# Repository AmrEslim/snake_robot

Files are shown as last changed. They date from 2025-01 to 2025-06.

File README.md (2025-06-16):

# snake_robot
# 🐍 Neurobiologically inspired control of a robot: Development and Control Strategies

This repository contains the development, design, and control strategies for a **Neurobiologically inspired control of a robot**, built as a Bachelor's thesis. The project focuses on **mechanical design, motion control, and CPG-based locomotion strategies**.

## 📖 Overview
The project explores:
- 🦴 **Hardware Design**: Modular snake-like body segments, 3D-printed joints.
- 🧠 **Control Strategies**: Central Pattern Generators (CPGs), Reinforcement Learning.
- 🎮 **Tests**: with Kinovea motion tracking.
- 🔬 **Experiments & Results**: Performance analysis, real-world testing.

## 📂 Repository Structure
📂 **hardware/** - STL files, electronics, and mechanical schematics  
📂 **software/** - Arduino IDE code control algorithms  
📂 **docs/** - Detailed documentation (see the [Wiki](https://github.com/AmrEslim/snake_robot/wiki))  
📂 **media/** - Photos, videos, and results

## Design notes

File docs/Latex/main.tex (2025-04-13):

\documentclass[12pt,a4paper]{report}
\usepackage[a4paper, margin=2.5cm]{geometry} 
\usepackage{graphicx}
\usepackage{float}
\usepackage[hidelinks]{hyperref}
\usepackage{amsmath, amssymb}
\usepackage{listings}
\usepackage[backend=biber,style=ieee,sorting=nty,maxnames=1,minnames=1]{biblatex}
\usepackage{csquotes}
\usepackage{algorithm}
\usepackage{algpseudocode}
\usepackage[utf8]{inputenc}
\usepackage{placeins}
\usepackage{float}
\usepackage{pgfplots}
\usepgfplotslibrary{units}
\usepackage{tikz}
\usepackage{minted}
\usepackage{xmpmulti}
\usepackage{animate}
\usepackage{multido}
\usepackage{svg}
\usetikzlibrary{snakes}
\usepackage{adjustbox}
\usepackage{pdfpages} 
\usepackage{chngcntr}
\usepackage{times}          % For Times New Roman font
\usepackage{microtype}      % For better typography in justified text
\usepackage{fancyhdr}       % For header and footer
\usepackage{ragged2e}       % For better justification
\usepackage{titlesec}       % For heading formatting
% Document settings according to university requirements
\renewcommand{\baselinestretch}{1.3}  % Line spacing between 1 and 1.3
\setlength{\parindent}{0pt}           % No paragraph indentation
\setlength{\parskip}{6pt}             % Paragraph spacing

% Make sure figures and tables are numbered continuously
\counterwithout{figure}{chapter}
\counterwithout{table}{chapter}
% Justify text with hyphenation
\hyphenpenalty=1000
\tolerance=1000
\emergencystretch=\maxdimen
\hbadness=10000
\doublehyphendemerits=10000
\finalhyphendemerits=5000

% Format chapter and section headings to make them stand out
\titleformat{\chapter}[display]
{\normalfont\huge\bfseries}{\chaptertitlename\ \thechapter}{20pt}{\Huge}
\titleformat{\section}
{\normalfont\large\bfseries}{\thesection}{1em}{}
\titlespacing*{\chapter}{0pt}{50pt}{40pt}
% Set up headers and footers
\pagestyle{fancy}
\fancyhf{}
\fancyhead[L]{\leftmark}    % Chapter name in the header
\fancyhead[R]{\thepage}     % Page number in the header
\renewcommand{\headrulewidth}{0.4pt}
\fancypagestyle{plain}{     % Style for chapter pages
  \fancyhf{}
  \fancyfoot[C]{\thepage}
  \renewcommand{\headrulewidth}{0pt}
}

\addbibresource{references.bib}

% Document settings following HTW guidelines
\renewcommand{\baselinestretch}{1.5}  % 1.5 line spacing
\setlength{\parindent}{0pt}  % No paragraph indentation
\setlength{\parskip}{6pt}    % Paragraph spacing

\titleformat{\chapter}[hang]
  {\normalfont\bfseries\Large}{\thechapter.}{10pt}{}

\begin{document}
% Include the title page
% Include the title page
\begin{titlepage}
    \centering
    \vspace*{0.5cm}
    % University logo at the top
    

    \vspace{1cm}
    \rule{\linewidth}{0.5mm}\\[0.4cm]
    {\Huge \textbf{Neurobiologically inspired control of a robot}}\\[0.3cm]
    \rule{\linewidth}{0.5mm}\\[1.5cm]

    {\LARGE Bachelorarbeit}\\[1.0cm]

    {\Large Computer Engineering}\\[1cm]

    {\large vorgelegt von}\\[0.3cm]
    {\Large Amr Eslim}\\[0.8cm]

    {\large Fachbereich 1}\\[1.0cm]

    {\large \textbf{Datum:}}\\
    {\large Berlin, \today}\\[1.0cm]

    {\large \textbf{Erstgutachter:} Prof. Dr. Jochen Kerdels}\\[0.3cm]
    {\large \textbf{Zweitgutachter:} Prof. Dr. Frank Bauernöppel}\\[1.5cm]

    % \includegraphics[width=0.3\textwidth]{media/snake_robot.jpg}
\end{titlepage}

\begin{abstract}
This thesis presents the design, implementation, and experimental evaluation of a neurobiologically inspired snake-like robot. Drawing from the locomotion mechanisms observed in biological snakes, the research develops a modular robotic system capable of executing multiple biologically authentic movement patterns. The work focuses on implementing Central Pattern Generator (CPG) inspired control algorithms to generate coordinated undulatory movements across the robot's segmented body. A 10-servo design with alternating horizontal and vertical actuation planes enables both lateral undulation and sidewinding locomotion patterns. The system utilizes an ESP32 microcontroller with WiFi connectivity to provide real-time control and parameter adjustment through a web-based interface. Three distinct robot configurations (baseline, with TPU-printed scales, and with PLA+ printed wheels) are experimentally evaluated to determine their effects on locomotion performance and energy consumption. Motion tracking analysis reveals differences in movement patterns between configurations, with wheels providing the most uniform progression during lateral undulation. Energy consumption measurements demonstrate that sidewinding requires more power than lateral undulation, and friction elements increase power requirements as well. The findings highlight the complex interplay between mechanical configuration, control parameters, and environmental interactions in biomimetic locomotion. This research contributes to the field of bioinspired robotics by providing insight into the design principles and control strategies for effective snake-like locomotion, with potential applications in search and rescue, pipeline inspection, and educational contexts.
\end{abstract}

\includepdf[pages=-]{Eigenstaendigkeitserklaerung.pdf}
% Start Roman numeral page numbering
\pagenumbering{Roman}
% Table of Contents
\tableofcontents
\listoffigures
\newpage
\listoftables
\newpage
% Start Arabic numeral page numbering with Introduction
\cleardoublepage
\pagenumbering{arabic}
%//////////////////
%//////////////////
%chapter 1
%//////////////////
%//////////////////
\chapter{ Introduction}
Snake-like robots represent a fascinating intersection of biological inspiration and robotic engineering, offering unique mobility solutions for complex environments. This chapter establishes the foundation for understanding bio-inspired snake robotics, examining the research context, motivations, and key objectives that drive this field forward. 

\section{Background and Motivation}
Snake robots have emerged as a promising technological innovation inspired by the locomotion mechanisms observed in biological snakes. These robots exhibit exceptional adaptability in navigating confined spaces and overcoming challenging terrains where conventional wheeled or legged robots struggle. Their unique ability to generate smooth and continuous movements makes them particularly suitable for applications such as search-and-rescue missions, pipeline inspection, and medical procedures requiring minimally invasive interventions \cite{transeth-2009, Hirose2004}.

The fundamental advantage of snake-like robots lies in their ability to replicate the efficient and versatile locomotion strategies of real snakes. By leveraging undulatory movements, these robots can traverse irregular surfaces, maneuver through narrow gaps, and maintain stability on diverse terrain \textcite{Seeja2022}. The inspiration from biological systems, coupled with advances in robotic control, has led to significant progress in the field, paving the way for innovative robotic applications.

\section{Research Objectives}
This research aims to contribute to the development of bio-inspired snake robots by focusing on the following key objectives:

\begin{itemize}
    \item Design and construct a modular snake robot with multiple degrees of freedom to enable flexible and adaptive movement.
    \item Develop and optimize biologically inspired control algorithms to achieve efficient and stable locomotion.
    \item Implement and evaluate different motion patterns, including lateral undulation and serpentine locomotion, to enhance adaptability across various environments.
    \item Analyze the robot's performance metrics across different terrain types to assess its effectiveness and versatility.
    \item Integrate a robust hardware and software control system to ensure reliable operation and real-time adaptability in dynamic conditions.
\end{itemize}

\section{Paper Structure}
Following the introduction, this thesis proceeds with a chapter on the state of the art, covering biological principles of snake locomotion as well as the historical development and current research status on snake robots and CPG networks. The third chapter presents the system design and implementation of the snake robot, including mechanical construction using Onshape, 3D printing, and integration of the ESP32 microcontroller with ten servo motors. The fourth chapter details the experimental results, analyzing movement patterns and power consumption. Finally, the thesis concludes with a summary of research findings, limitations of the current implementation, and suggestions for future improvements. Supplementary technical documentation regarding hardware and software is provided in the appendix.

%//////////////////
%//////////////////
%chapter 2
%//////////////////
%//////////////////
\chapter{State of the Art}

This chapter reviews the biological principles of snake locomotion, including natural movement patterns and biomechanics. It also explores the historical development and current state of snake robot research, covering simulation and modeling approaches, biologically inspired robotic designs, and neurological models for locomotion control.

\section{Biological Snake Locomotion}
Snake locomotion has been extensively studied as a foundation for bio-inspired robotics. According to \textcite{liljeback-2013}, snake motion can be characterized by several distinct patterns, each optimized for different environmental conditions and objectives. These patterns have been widely implemented in robotic systems to improve their adaptability and efficiency in traversing complex environments.
Further investigations have examined the biomechanical principles underlying these motion patterns, contributing to the development of advanced control strategies \cite{lamping-2022}.

\subsection{Natural Snake Movement Patterns}
The primary motion patterns observed in biological snakes include:

\subsubsection{Lateral Undulation}
Lateral undulation, also known as serpentine motion, is the most common form of snake locomotion \textcite{liljeback-2013}. In this pattern, the snake creates a series of smooth curves that propagate from head to tail, generating forward thrust through the interaction with ground irregularities. \textcite{liljeback-2013} describe this as a wave-like motion where the snake's body follows the path traced by its head, with each segment of the body following the same spatial curve but with a time delay. 

\subsubsection{Rectilinear Motion}
According to \textcite{Zhenli2006} rectilinear locomotion occurs when "the skin of the ventral surface is moved forward and backward by strong muscles and the broad belly scales grip the ground, moving the snake forward in a straight line." The authors note that this form of locomotion "is used only by the heavier-bodied snakes."

\subsubsection{Concertina Locomotion} Concertina locomotion is named after a small accordion instrument, illustrating how the snake periodically folds and stretches its body to move forward. In this gait, the snake will anchor part of its body against the ground (or against a tunnel wall, tree branch, etc.), while other sections extend forward, after which the newly extended portion forms a new anchor and pulls the rest of the body along \cite{Zhenli2006}. note that this pattern is especially prevalent in constrained or narrow spaces, and it is often used for crossing smooth surfaces or climbing where other gaits may prove less effective.

\subsubsection{Sidewinding}
Sidewinding is "probably the most astonishing gait to observe and is mostly used by snakes in the desert" \cite{transeth-2009}. During this locomotion, "the snake lifts and curves its body leaving short, parallel marks on the ground while moving at an inclined angle" \cite{transeth-2009}. Unlike other gaits like lateral undulation, sidewinding involves "brief static contact between the body of the snake and the ground" \cite{transeth-2009}. This movement pattern is particularly useful "on surfaces with low shear such as sand" where snakes can achieve velocities up to 3 km/h \cite{transeth-2009}.

\subsection{Biomechanical Principles}
The effectiveness of snake locomotion relies on several key physical principles:

\subsubsection{Friction Models}
  As \textcite{lamping-2022} thoroughly analyze, anisotropic friction is crucial for effective snake movement. The contrast in forward versus reverse friction coefficients drives directional locomotion. This principle is significant for designing snake robots, which often require artificial scales or surface modifications to mimic this property. These mechanisms that enhance friction in snake-like robots are vital to improving their ability to adapt to a wide range of surfaces.
 
\subsubsection{Propulsion Mechanics}
The generation of propulsive forces in snake locomotion is achieved through strategic interactions with environmental push-points, where reaction forces contribute to forward movement. \textcite{Bayraktaroglu2006} describe how a snake-like robot mimics natural lateral undulation by utilizing push-points in the environment. Each module follows its predecessor, ensuring coordinated motion, while the orientation of reaction forces determines the overall direction of movement. The applied motor control inputs facilitate continuous progression similar to biological snakes.
Additionally, rhythmic motion patterns are regulated by neuronal circuits known as Central Pattern Generators (CPGs), described further in Section \ref{sec:neurological_models}.

\section{Snake Robots: State of the Art}

This section examines the evolution of snake robotics from its inception to current state-of-the-art implementations, highlighting key developments in mechanical design, control strategies, and application domains.

\subsection{Historical Development}
The historical evolution of snake robotics commenced with Hirose's pioneering work in 1972, developing the Active Cord Mechanism (ACM III), which became the foundational design for snake robots. Hirose introduced the concept of modularity and redundancy, emphasizing adaptability to challenging terrains through serpentine motion patterns \cite{transeth-2009}. His initial robot designs featured serially connected joints capable of undulatory locomotion, thus setting a standard for robust, modular robotic systems \cite{Hirose2004}.

Building upon Hirose's foundational contributions, research diversified into wheeled and wheel-less robotic designs. Initially, passive wheels were utilized to facilitate smooth movements on structured surfaces; however, these were limited to artificially prepared environments \cite{Bayraktaroglu2006}. Subsequently, a shift toward wheel-less snake robots was driven by a desire to replicate natural snake locomotion more accurately, leading to advancements in mechanical and control innovations \cite{transeth-2009}.

\subsection{Current Research Directions}
Contemporary research in snake robotics is focused on enhancing locomotion efficiency, adaptability, and control mechanisms. Several key areas of investigation include:

\subsubsection{Control Systems}

Central Pattern Generators (CPGs) have been increasingly applied to snake-like robots for generating rhythmic movements. \textcite{Seeja2022} discuss CPG-based algorithms enabling robots to dynamically adjust trajectories, facilitating obstacle avoidance and smooth turning motions. Sensory feedback integration further improves collision detection and adaptive movement capabilities.

\subsubsection{Alternative Locomotion Strategies}
\textcite{yamano-2023} propose a rolling motion strategy for snake-like robots that enhances efficiency by utilizing a shift in the center of gravity (COG). Their approach divides the rolling motion into four distinct phases: (1) the kick stage, where the robot’s head or tail moves to initiate ground contact and generate rolling motion; (2) COG shift stage I, in which a heavier link at the head or tail moves forward to reposition the COG; (3) COG shift stage II, where the same link is raised to further adjust the COG; and (4) the rolling stage, where gravity facilitates continuous rolling motion.

\subsubsection{Mechanical Design and Adaptability}
The impact of mechanical parameters, particularly scale angles and friction coefficients, on the locomotion of snake robots has been extensively studied. Research by \textcite{shen-2021} demonstrated that the angle of the robot’s scales can be dynamically adjusted using air pressure, directly influencing its movement efficiency. Their experiments revealed that an optimal anchoring coefficient is achieved when the scale angle is around 26.7° at a pressure of 12 kPa, significantly improving forward propulsion. Conversely, when the pressure exceeds 22 kPa, the scales flip direction, enabling backward locomotion. This adaptive approach mimics biological snake adaptations by altering surface friction to enhance traction and maneuverability.

\subsection{Simulation and Modeling}
Accurate modeling is essential for designing and optimizing snake robot locomotion. \textcite{liljeback-2013} provide a foundational analysis of lateral undulation, introducing a simplified dynamic model for control design and stability analysis. Their study highlights that effective locomotion control must incorporate time-varying strategies, as static control laws fail to stabilize the system due to its inherent dynamics. Using averaging theory, they derived fundamental relationships between gait parameters and forward velocity, showing that the robot’s motion can be analytically predicted and optimized based on these parameters. This work has been instrumental in developing physics-based simulations that enable rapid prototyping and validation of locomotion strategies.

An additional contribution to simulation methodologies comes from \textcite{yogesh2023snake}, who provides open-source simulation tools for snake robot modeling. These practical implementations facilitate experimentation with different control strategies and locomotion patterns, supporting researchers in optimizing robot performance before physical deployment.

\subsection{Biologically Inspired Snake-like Robots}
Bio-inspired design principles continue to drive innovations in snake robotics. \textcite{Mohammed2016} developed a 3D printed modular snake robot that integrates flexible joint structures, enhancing both maneuverability and robustness. Their research highlights the benefits of modularity, where each module functions as a single rotational joint with one degree of freedom (DOF). The robot's structure allows for movement across multiple axes, enabling adaptability in various applications, such as search-and-rescue and medical robotics.

Building on this, \textcite{Arachchige2021} explored the potential of soft robotic snakes (SRS) by incorporating spatial bending capabilities to extend locomotion beyond conventional planar gaits. Their study demonstrates how continuous and smooth bending enables snake robots to better replicate biological movement, allowing for improved adaptability in climbing, swimming, and traversing complex terrains. These advancements highlight how soft robotics principles enhance maneuverability while maintaining structural integrity and operational efficiency.

\section{Neurological Models of Snake Locomotion}
\label{sec:neurological_models}
The locomotion of snakes has been extensively studied, revealing that their movement is governed by neural circuits that enables adaptive and rhythmic motion. This capability is controlled by Central Pattern Generators (CPGs), which are neural circuits responsible for generating rhythmic outputs without requiring continuous sensory feedback. These circuits, located within the spinal cord, play a fundamental role in orchestrating rhythmic behaviors such as walking, swimming, and crawling in both vertebrates and invertebrates \cite{MARDER2001R986}

\subsection{Central Pattern Generator (CPG) Model}

CPGs, fundamental to locomotion control, are extensively modeled to replicate the rhythmic patterns of snake locomotion. They typically comprise coupled neural oscillators that produce rhythmic signals with stable oscillations and phase-shifted outputs for coordinated joint movements \cite{wang2020cpg}. Various approaches to CPG modeling have been proposed:

\FloatBarrier
\subsubsection{Mutual Inhibitory CPGs}

One of the fundamental architectures for generating rhythmic motion is the mutual inhibitory CPG model shown in Figure~\ref{fig:mutual_inhibitory_cpg}, which consists of neuron pairs that reciprocally inhibit each other, leading to stable oscillations. This architecture ensures continuous rhythmic movement. However, it lacks adaptability to environmental variations because it does not inherently produce sustained oscillations without additional adaptation mechanisms \cite{Lu2006}.

\begin{figure}[H]
\centering
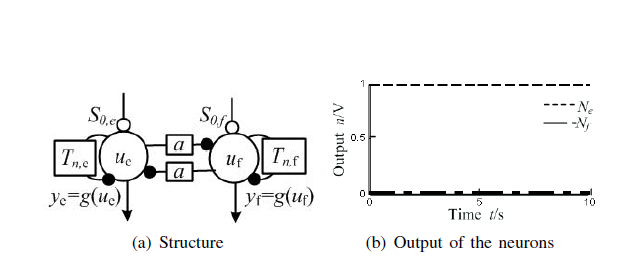
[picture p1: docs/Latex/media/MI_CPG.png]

\caption{Mutual inhibitory CPG model \cite{Lu2006}. This model illustrates pairs of neurons reciprocally inhibiting each other, creating stable rhythmic oscillations.}
\label{fig:mutual_inhibitory_cpg}
\end{figure}

\subsubsection{Cyclic Inhibitory CPGs}

Cyclic inhibitory CPG models address the limitations of mutual inhibitory architectures by incorporating feedback loops that enable the system to maintain oscillatory activity over time. These models involve interconnected neurons in a cyclic inhibitory structure (see Figure \ref{fig:cyclic_inhibitory_cpg}), allowing for sustained and coordinated oscillations. This design proves particularly effective in generating stable 3D locomotion, as it enhances phase synchronization across multiple joints. Studies have demonstrated the effectiveness of this model in achieving robust serpentine motion, making it a preferable choice for controlling the locomotion of snake-like robots \cite{Lu2006}.

\begin{figure}[H]
\centering
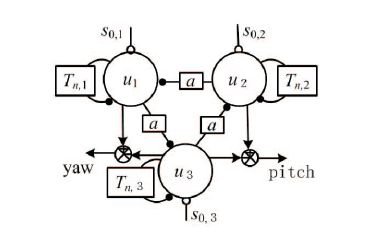
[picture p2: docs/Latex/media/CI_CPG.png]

\caption{Cyclic inhibitory CPG model \cite{Lu2006}}
\label{fig:cyclic_inhibitory_cpg}
\end{figure}

\subsubsection{Sensory Feedback-Integrated CPGs}
Recent advancements in CPG modeling incorporate sensory feedback mechanisms, allowing adaptive locomotion. These models integrate sensory information through sensory interneurons (SIN), which relay environmental data back to the CPG, enabling real-time adjustments to oscillatory parameters \cite{Inoue2007}. For instance, \textcite{Inoue2007} implemented a CPG-based control system where sensory input was processed by SIN and fed back into the CPG, enhancing the robot's ability to adapt to variations in ground friction.

\subsubsection{Evolutionary and Learning-Based CPGs}
Machine learning and evolutionary algorithms have been applied to optimize CPG parameters for snake locomotion. By employing genetic algorithms (GA), researchers have enabled robots to autonomously refine their locomotion patterns in response to different terrains and obstacles \cite{Inoue2007}. Specifically, \textcite{Inoue2007} used GA to evolve CPG parameters that maximize adaptability across varying friction conditions, demonstrating that multi-environment performance-based evaluation functions enhance adaptive locomotion.

\subsection{Implementation Considerations}
When implementing CPG-based control, several key factors must be considered:
\begin{itemize}
    \item Phase Relationships Between Segments: To achieve effective serpentine locomotion, it is essential to maintain a consistent phase difference between joint oscillations. This phase control ensures synchronized movement, allowing the robot to generate propulsion force through interactions with the ground \cite{Norzalilah2014}.
    \item Coupling Strengths Between Oscillators: The coordination between different segments of a CPG network is influenced by the strength of the connections between oscillators. Proper tuning of descending and ascending coupling pathways is necessary to ensure segmental synchronization, which requires detailed anatomical and electrophysiological studies \cite{MARDER2001R986}.
    \item Adaptation Mechanisms for Environmental Feedback: A robust CPG-based system must integrate sensory feedback to adapt to environmental variations. Sensory inputs, such as ground reaction forces or muscle length changes, can be fed back into the CPG network to enhance stability and improve locomotion resilience against disturbances \cite{Inoue2007}.
    \item Stability of Rhythm Generation: The stability of rhythmic motion depends on ensuring bounded and well-defined oscillatory behavior. Mathematical conditions such as Lipschitz continuity help establish the existence and uniqueness of stable rhythmic solutions in CPG models, preventing disruptions in locomotion patterns \cite{Zhenli2006}.
\end{itemize}

These models provide a foundation for developing bio-inspired control systems that can generate smooth, coordinated motion patterns while maintaining adaptability to environmental changes.

\subsection{Mathematical Representation of CPG Networks}

The neural control system of a snake-like robot can be mathematically modeled as a network of coupled oscillators. As described by \textcite{wang2020cpg}. each oscillator in the network represents a segmental neural circuit. The system is structured as a single-chain bidirectional coupling network, where each connection between oscillators is defined by a phase lag parameter. The network's dynamics are governed by the following set of differential equations:

\begin{equation}
    \dot{\theta}_k =
    \begin{cases} 
        2\pi v + w \sin(\theta_2 - \theta_1 + \phi), & k = 1 \\
        2\pi v + w \left[\sin(\theta_{k-1} - \theta_k - \phi) + \sin(\theta_{k+1} - \theta_k + \phi)\right], & 2 \leq k \leq N-1 \\
        2\pi v + w \sin(\theta_{N-1} - \theta_N - \phi), & k = N
    \end{cases}
\end{equation}

where \( \theta_k \) represents the phase of the \( k \)-th oscillator, \( v \) denotes the intrinsic oscillation frequency, and \( w \) is the coupling strength between oscillators. The output of each oscillator, corresponding to the joint angle in a snake-like robot, is given by:

\begin{equation}
    \phi_k = A \cos(\theta_k), \quad 1 \leq k \leq N
\end{equation}

where \( A \) represents the oscillation amplitude. This mathematical formulation provides a precise method for generating rhythmic movement, crucial for implementing bio-inspired locomotion strategies in snake-like robots \cite{wang2020cpg}.

%//////////////////
%//////////////////
%chapter 3
%//////////////////
%//////////////////

\chapter{System Design, Implementation, and Details}

This chapter presents the complete design and implementation of the bio-inspired snake robot, focusing on its hardware architecture, control system, and motion generation. Inspired by biological snake locomotion patterns, the system employs Central Pattern Generator (CPG)-based control strategies.

\section{Evolution of System Design}
The snake robot underwent several iterations, each driven by practical testing and the desire to overcome early design limitations. The first prototype was built around an STM32-L432KC microcontroller with only preprogrammed parameters, offering no interface to start, stop, or adjust the locomotion algorithm in real time. All circuitry, including the buck converters, was centralized in the head module, making it disproportionately large and heavy compared to the rest of the body. This imbalance placed excessive strain on the front servo motor, reducing maneuverability and overall efficiency.

Motivated by these limitations, a new approach centered on the ESP32 microcontroller was adopted. The ESP32 not only offers more capable processing but also provides built-in wireless connectivity, allowing for a WiFi-based interface to control motion parameters remotely. Beyond WiFi, the ESP32 facilitates future expansion via ESP-NOW for direct controller-to-controller links, making it possible to develop a dedicated handheld remote or integrate additional sensing modules without physical wiring. Familiarity with the ESP32 development environment and libraries further justified its selection over the STM32 platform.

In parallel with changing the microcontroller, the mechanical design was refined to address structural weaknesses. Rather than relying on a single contact point in each joint, two robust contact points were introduced, significantly improving stability and mitigating stresses that lead to early mechanical failures. A vertical joint was also added to enable out-of-plane motion, expanding the robot’s maneuverability beyond simple horizontal undulations and paving the way for more complex locomotion strategies.

\subsection{Distributed Power and Noise Mitigation}
Shifting the power architecture to a distributed design represented another key enhancement. Instead of locating all buck converters in the head, individual converters were placed near each servo motor. This arrangement reduced the length and complexity of wiring, requiring only a single power line routed from the battery to each converter. Although this layout made the design cleaner and lighter, it also introduced an issue with signal noise: the servos occasionally moved erratically or exhibited jitter.

A detailed investigation revealed that the combination of servo control signals and distributed power lines led to unwanted interference. To counteract this noise, a 16\,V/100\,$\mu$F capacitor was placed on each buck converter output, acting as a local power reservoir. Additionally, each servo signal line was equipped with a 10\,k$\Omega$ pull-down resistor, which helped stabilize the control signals. These hardware modifications effectively eliminated the jitter and restored precise servo actuation.

\subsection{Battery Selection and Current Sensing}
After refining the cabling and completing initial motion tests, it became evident that the chosen battery’s built-in current-limiting protection would occasionally trigger and power down the system. During peak load conditions, especially when multiple servos actuated simultaneously, the protection circuit perceived an overcurrent event and disconnected the output. 

To address this, a standard 18650 Li-ion cell without built-in current-limiting circuitry was chosen as the primary power source. Realizing that accurate power monitoring would be critical, an ACS712-based current sensor was integrated into the design. By measuring the instantaneous current draw, the control software can monitor power consumption in real time, log average and peak current usage, and provide valuable diagnostics to the user. 

\section{Hardware Implementation}
Following the above design decisions, the mechanical and electronic structures were consolidated into a modular system. The head module now houses the ESP32, the main battery, the current sensor, and the primary wiring harnesses routed through a dedicated cable management channel. Buck converters are distributed such that each servo has a nearby power regulator, ensuring stable voltage supply and reducing the chance of voltage drops or noise accumulation.

Mechanically, each segment features two robust hinge contact points to support lateral and vertical movements. A vertical joint segment is inserted at intervals to allow out-of-plane motion, enhancing maneuverability beyond simple sinusoidal undulation. The tail segment carries no electronics and adds more of a Visual effect than a practical one.

\section{Control System Architecture}
Leveraging the ESP32’s computing and connectivity, the control system adopts a bio-inspired Central Pattern Generator (CPG) approach to coordinate the robot’s undulations. The CPG model allows for parameterized control over amplitude, phase offset, and frequency, all of which can be modified in real time via a web-based interface hosted directly on the ESP32.

During operation, the ESP32 creates an access point through which a user can connect via a standard web browser. Motion parameters, start/stop commands, and other real-time adjustments are transmitted via HTTP POST requests, immediately influencing the CPG outputs and servo drive signals. This wireless interface greatly simplifies experimentation with different locomotion patterns, as it eliminates the need for physical programming cables and manual adjustments.

Future expansions include employing ESP-NOW to link the snake robot’s ESP32 with a remote-control unit, also based on an ESP32, enabling direct, low-latency communication. This setup could further extend to multiple sensory modules or even swarm collaboration between multiple robots. In summary, the move to an ESP32 platform, combined with distributed power regulation, vertical joint integration, and robust noise suppression, has significantly enhanced both the mechanical and electronic performance of the snake robot while laying a flexible foundation for continued innovation.

\begin{figure}[h]
\centering
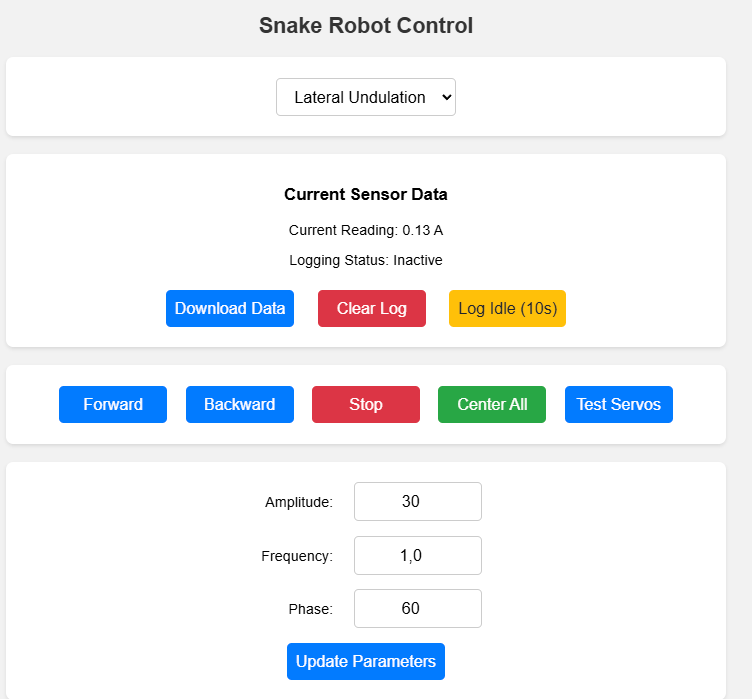
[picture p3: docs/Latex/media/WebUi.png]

\caption{Web Ui to control the snake's behavier}
\end{figure}

\section{Motion Pattern Generation}
Locomotion is generated using biologically inspired Central Pattern Generator (CPG) algorithms, primarily implementing lateral undulation and sidewinding patterns. The control system is designed to mimic the neurobiological motion generation found in biological snakes, where rhythmic patterns emerge from neural networks without requiring continuous sensory feedback \parencite{MARDER2001R986}. 

\subsection{Lateral Undulation}
Lateral undulation is the most common locomotion pattern observed in biological snakes and is particularly effective on flat surfaces with friction \parencite{transeth-2009}. In our implementation, this pattern follows a traveling wave function, where each servo's angular displacement is determined by a sinusoidal function:

\begin{equation}
\theta_i(t) = A \sin(\omega t + \phi_i) + \theta_{\text{offset}}
\end{equation}

Where:
\begin{itemize}
    \item $\theta_i(t)$ is the angle of the $i$-th servo at time $t$,
    \item $A$ is the amplitude of the wave (controlled via the interface as \texttt{amplitude}),
    \item $\omega = 2\pi f$ is the angular frequency based on frequency $f$ (controlled as \texttt{frequency}),
    \item $\phi_i$ is the phase offset for the $i$-th segment, calculated as $i \cdot \text{phaseOffset}$,
    \item $\theta_{\text{offset}}$ is the center position (set to 90° in our implementation).
\end{itemize}

Looking at the implementation, the lateral undulation is generated in the \break \texttt{updateServosLateralUndulation()} function. The time-dependent parameter is calculated as:

\begin{equation}
\text{timeScale} = t \cdot 0.001 \cdot f \cdot 2\pi
\end{equation}

Where $t$ is the system time in milliseconds from the \texttt{millis()} function, scaled to seconds with the 0.001 factor. This provides the temporal component of the wave.

For each horizontal servo in the array, a phase offset is applied depending on the segment's position and the desired direction of travel:

\begin{equation}
\text{segmentPhase} = 
\begin{cases}
(N_h - 1 - i) \cdot \phi & \text{for forward motion} \\
i \cdot \phi & \text{for backward motion}
\end{cases}
\end{equation}

Where $N_h$ is the number of horizontal servos (7 in our implementation), $i$ is the index of the horizontal servo, and $\phi$ is the phase offset in radians. The inversion of phase progression for different directions creates a traveling wave that moves either anteriorly or posteriorly along the robot's body, similar to how biological snakes propagate waves from head to tail during forward motion \parencite{liljeback-2013}.

The final angular position of each servo is calculated as:

\begin{equation}
\theta_i = \theta_{\text{center}} + A \cdot \sin(\text{timeScale} + \text{segmentPhase})
\end{equation}

An important consideration in our implementation is that the phase relationship definition for forward and backward motion is carefully constructed to ensure the wave propagates in the correct direction. For forward motion, the wave must travel from the tail toward the head (posteroanterior propagation), creating a pushing force against the ground that propels the robot forward. Our implementation achieves this by inverting the phase index calculation for forward motion, ensuring the wave propagates in the correct biological direction.

\begin{figure}
  \centering
  \animategraphics[controls,width=0.8\textwidth]{12}{media/Lateral/ezgif-frame-}{1}{33}
  \caption{Lateral Undulation simulation showing the propagation of the sinusoidal wave through the robot's body. Note how the wave travels from tail to head during forward motion.}
  \label{fig:lateral-anim}
\end{figure}

\FloatBarrier
\subsection{Sidewinding}
Sidewinding is a more complex locomotion pattern used by snakes in low-friction environments such as sand or smooth surfaces \cite{transeth-2009}. It combines horizontal and vertical wave motions with a specific phase relationship between them to generate a lifting effect. This implementation follows concepts from studies like \textcite{yamano-2023} and is formulated as:

\begin{equation}
\theta_{i,h}(t) = A_h \sin(\omega t + \phi_{i,h}) + \theta_{\text{center}}
\end{equation}

\begin{equation}
\theta_{i,v}(t) = A_v \sin(\omega t + \phi_{i,v} + \Delta\phi) + \theta_{\text{center}}
\end{equation}

Where:
\begin{itemize}
    \item $\theta_{i,h}(t)$ represents the horizontal actuation of the $i$-th servo,
    \item $\theta_{i,v}(t)$ represents the vertical actuation,
    \item $A_h$ and $A_v$ are the respective amplitudes of horizontal and vertical motion (set as \texttt{amplitude} and \texttt{verticalAmplitude} in our implementation),
    \item $\phi_{i,h}$ and $\phi_{i,v}$ are the phase offsets for each segment,
    \item $\Delta\phi$ is the phase difference between horizontal and vertical waves (set to 90° in our implementation).
\end{itemize}

The implementation in \texttt{updateServosSidewinding()} handles both horizontal and vertical servos differently. For horizontal servos, the phase calculation considers the direction of travel:

\begin{equation}
\phi_{i,h} = 
\begin{cases}
(N_h - 1 - i) \cdot \phi & \text{for forward motion} \\
i \cdot \phi & \text{for backward motion}
\end{cases}
\end{equation}

For vertical servos, the phase relationship includes both the progressive phase based on segment position and the additional vertical phase offset:

\begin{equation}
\phi_{i,v} = 
\begin{cases}
(N_v - 1 - i) \cdot \phi + \phi_{\text{vertical}} & \text{for forward motion} \\
i \cdot \phi + \phi_{\text{vertical}} & \text{for backward motion}
\end{cases}
\end{equation}

Where $N_v$ is the number of vertical servos (3 in our robot), $i$ is the index of the vertical servo, $\phi$ is the phase offset, and $\phi_{\text{vertical}}$ is the additional phase offset between horizontal and vertical waves (set to 90° or $\pi/2$ radians).

This configuration creates a coordinated lifting and lateral movement that allows the robot to "sidestep" across surfaces. The vertical wave component causes segments to lift off the ground in sequence, while the horizontal component creates the necessary lateral displacement. The 90° phase difference between the horizontal and vertical waves is critical, as it ensures that maximum vertical displacement occurs at the appropriate point in the horizontal cycle \parencite{yamano-2023}.

Our specific implementation of the vertical servo control in sidewinding uses a more complex phase calculation that accounts not only for the segment position but also adjusts for the direction of travel. For forward motion, the phase progression is inverted similarly to the horizontal servos, but with an adjustment for the different number of vertical servos:

\begin{equation}
\phi_{i,v} = (N_t - N_h - 1 - i) \cdot \phi + \phi_{\text{vertical}}
\end{equation}

Where $N_t$ is the total number of servos (10) and $N_h$ is the number of horizontal servos (7). This ensures proper coordination between horizontal and vertical movements during direction changes.

\begin{figure}
  \centering
  \animategraphics[controls,width=0.8\textwidth]{12}{media/Side/ezgif-frame-}{1}{33}
  \caption{Sidewinding movement simulation showing the combined effect of horizontal and vertical wave propagation. Note the diagonal lifting pattern that creates the characteristic sidewinding motion.}
  \label{fig:side-anim}
\end{figure}

\subsection{Servo Layout and Configuration}
The physical arrangement of servos in our snake robot follows a specific pattern designed to support both locomotion modes effectively. The robot consists of 10 servo modules arranged in an alternating pattern of horizontal and vertical actuators:

\begin{equation}
\text{servoLayout} = [1, 0, 1, 1, 0, 1, 1, 0, 1, 1]
\end{equation}

Where 1 represents a horizontal servo (7 total) and 0 represents a vertical servo (3 total). This asymmetric distribution was chosen based on preliminary testing that showed better performance with more horizontal actuators, while still providing sufficient vertical control for effective sidewinding.

\begin{figure}
  \centering
  \includesvg[width=0.9\textwidth]{media/svg/Layout_Diagram.svg}
  \caption{Physical arrangement of servos in the snake robot showing the alternating pattern of horizontal (H) and vertical (V) actuators. The diagram illustrates how each servo's axis of rotation contributes to the overall motion pattern.}
  \label{fig:servo-layout}
\end{figure}

\subsection{Parameter Control and Adaptation}
The implementation allows for real-time adjustment of key locomotion parameters through the web interface:

\begin{itemize}
    \item \textbf{Amplitude}: Controls the maximum angular displacement of servos (10°-45°)
    \item \textbf{Frequency}: Determines the speed of wave propagation (0.1-2.0 Hz)
    \item \textbf{Phase Offset}: Sets the phase difference between adjacent segments (30°-90°)
\end{itemize}

These parameters can be adjusted to optimize the robot's movement across different surfaces and conditions. The interface constrains these values within practical ranges to ensure stable locomotion while preventing mechanical stress on the servos.

Our implementation uses the constrain() function to ensure parameters remain within safe operating ranges:

\begin{equation}
\text{amplitude} = \text{constrain}(\text{amplitude}, 10.0, 45.0)
\end{equation}

\begin{equation}
\text{frequency} = \text{constrain}(\text{frequency}, 0.1, 2.0)
\end{equation}

\begin{equation}
\text{phaseOffset} = \text{constrain}(\text{phaseOffset}, 30.0, 90.0)
\end{equation}

The effects of these parameters on locomotion performance are illustrated in Figure \ref{fig:param-effects}.

\subsection{Implementation of CPG Network}
While traditional CPG implementations often use coupled oscillator networks, 
% \parencite{wang2020cpg}
 our approach uses a simplified mathematical model that achieves equivalent functionality. The sinusoidal wave generation with appropriate phase relationships effectively simulates the output of a CPG network, where:

\begin{equation}
\text{CPG}_i(t) = \sin(\omega t + \phi_i)
\end{equation}

This approach is computationally efficient while still capturing the essential characteristics of biological CPGs. The phase relationships between segments create an interconnected system similar to the coupled oscillators in biological neural circuits.

The update frequency of the motion generation system is set to 50 Hz (with an interval of 20 ms), ensuring smooth motion while being well within the processing capabilities of the ESP32 microcontroller. This frequency is sufficient to maintain fluid, continuous movement patterns while allowing for other system operations such as handling web server requests and data logging.

\subsection{Direction Control}
The direction of travel is controlled by inverting the phase progression along the body. For forward motion, the phase offset increases from head to tail, while for backward motion, the phase progression is reversed. This mimics the biological control strategy in which the direction of wave propagation determines the direction of movement.

In the implementation, this is achieved through conditional logic in both locomotion functions that selects the appropriate phase calculation based on the \texttt{forwardDirection} boolean variable. This direction control is critical for both locomotion patterns, though the specific implementation differs slightly between lateral undulation and sidewinding to account for the different servo configurations and wave propagation patterns.

A key insight from our implementation is that a critical factor for effective direction control is ensuring the proper relationship between the direction of wave propagation and the desired movement direction. For lateral undulation, forward motion requires a posteroanterior wave (tail to head), while backward motion requires an anteroposterior wave (head to tail).
%//////////////////
%//////////////////
%chapter 4
%//////////////////
%//////////////////
\chapter{Experimental Results and Analysis}
This chapter presents the performance evaluation of the snake robot. It includes detailed analyses of the movement, and testing with different friction modules. Specific evaluations include motion pattern analysis and power consumption.

\section{Experimental Setup}
To evaluate the performance of the neurobiologically inspired snake robot, a series of experiments was conducted under controlled conditions. The primary objective was to assess the different locomotion patterns and analyze how various robot configurations influence movement capabilities.

\subsection{Testing Environment}
All experiments were conducted on laminate wood flooring, providing a low-friction, uniform surface for consistent testing conditions. For quantitative movement analysis, a testing area was created using:
\begin{itemize}
    \item A horizontal strip of cardboard extending 130 cm, marked with tape at 10 cm intervals
    \item A vertical strip of cardboard extending 70 cm, marked with tape at 10 cm intervals
\end{itemize}

This grid setup enabled precise tracking of the robot's two-dimensional movement path, providing reference points for subsequent video analysis. The grid layout is illustrated in Figure~\ref{fig:tracking_setup}.

\begin{figure}[H]
    \centering
    \begin{tikzpicture}
        % Draw the testing area
        \draw[thick] (0,0) rectangle (13,6);
        
        % Draw horizontal markers
        \foreach \x in {0,1,...,13}
            \draw[thick] (\x,0) -- (\x,-0.3) node[below] {\x0};
        
        % Draw vertical markers
        \foreach \y in {0,1,...,6}
            \draw[thick] (0,\y) -- (-0.3,\y) node[left] {\y0};
        
        % Draw snake robot schematically
        \draw[thick, snake=snake, segment amplitude=0.5, segment length=1cm] (2,3) -- (6,3);
        
        % Draw tracking markers
        \filldraw[black] (2,3) circle (0.2) node[above] {Tail marker};
        \filldraw[black] (6,3) circle (0.2) node[above] {Head marker};
    \end{tikzpicture}
    \caption{Experimental setup showing the testing area with measurement grid and tracking markers on the snake robot.}
    \label{fig:tracking_setup}
\end{figure}

\begin{figure}[h]
\centering
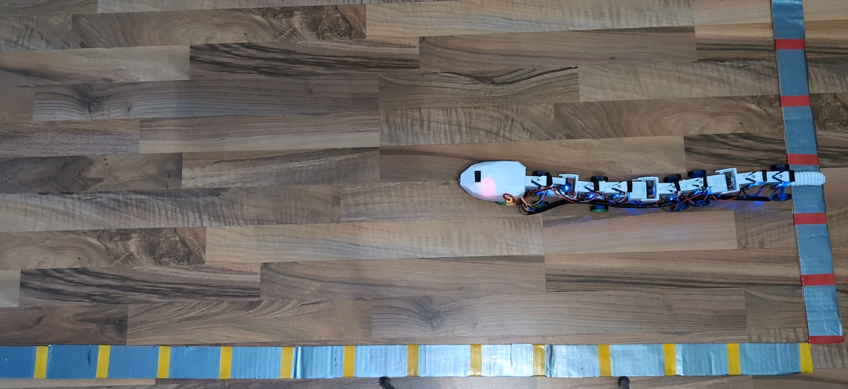
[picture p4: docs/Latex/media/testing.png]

\caption{Picture of the Experimental setup}
\end{figure}

%//////////////////////////////////
%surface beschreibung.............
%//////////////////////////////////

\subsection{Robot Configurations}
The robot was tested in three distinct configurations to determine the optimal setup for locomotion on laminate surfaces:
\begin{itemize}
    \item With TPU-printed passive scales (biomimetic approach)
    \item With wheels on each segment (traditional robotic approach)
    \item Baseline configuration without additional friction elements
\end{itemize}

Each configuration was evaluated using two locomotion patterns to assess how different friction mechanisms affect movement behavior on the laminate surface.

\subsection{Motion Patterns}
Two primary locomotion patterns were implemented and tested:
\begin{itemize}
    \item Lateral undulation: The most common snake movement pattern, characterized by horizontal sinusoidal waves propagating along the body
    \item Sidewinding: A more complex 3D motion pattern combining horizontal and vertical waves with a phase difference
\end{itemize}

For each pattern, the control parameters in the ESP32 firmware were set to standard values (amplitude: 30°, frequency: 1.0 Hz, phase offset: 60° for lateral undulation.

\subsection{Data Collection Methodology}
To analyze the locomotion performance, the robot was marked with Red tape indicators at its head and tail sections. Movement was captured on video and analyzed using Kinovea software, a specialized motion analysis tool that enables tracking of markers throughout the movement sequence.

The data collection process consisted of the following steps:
\begin{enumerate}
    \item The snake robot was positioned at the grid origin with its markers clearly visible
    \item The robot was activated using the web interface with the selected locomotion pattern
    \item Video footage was recorded as the robot moved across the measurement grid
    \item Kinovea was used to calibrate the video using the strip of cardboards on both axes as illisturated in FigureFigure~\ref{fig:kinovea}
    \item Head and tail markers were tracked frame by frame throughout the robot's movement
    \item Tracking data was exported as CSV files containing positional information over time (including horizontal position, vertical position)
    \item Current consumption was recorded using the ACS712 sensor integrated into the robot's power system
    \item The data was processed and then Visualized in graphs using a react based code, which was compiled on https://codesandbox.io/. This has simplified the process by also having interactive graphs.
\end{enumerate}

For each configuration and locomotion pattern, multiple trials were conducted to ensure consistency of results. The movement durations varied between trials, with lateral undulation tests lasting 5-10 seconds and sidewinding tests lasting 4-8 seconds, depending on the configuration.

\begin{figure}[H]
\centering
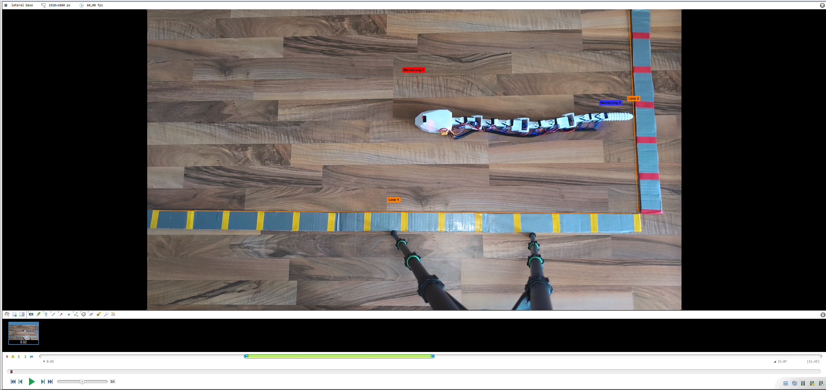
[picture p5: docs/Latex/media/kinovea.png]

\caption{Kinovea motion analysis app interface}
\label{fig:kinovea}
\end{figure}

%////////////////////////////////////////////

\section{Locomotion Performance Results}
This section presents a comprehensive analysis of the snake robot's locomotion capabilities based on systematic experimental trials. Multiple configurations were tested to evaluate performance metrics. Tracking data was collected using visual markers positioned at the head and tail segments, enabling quantitative analysis of the robot's movement trajectories under various conditions. The experiments were conducted on a standardized laminate wood surface to ensure consistent environmental conditions across all trials.

\subsection{Effect of Configuration on Locomotion}
The robot configuration significantly influenced locomotion movement patterns on the laminate wood surface. Analysis of the tracking data revealed distinct movement characteristics for each configuration. Each experiment was repeated at least three times to establish reliable patterns, which were observed with minimal deviations across trials.

\subsection{Locomotion Pattern Analysis}
Detailed analysis of the tracking data revealed distinct movement characteristics across different robot configurations and locomotion modes. By examining the trajectories of both head and tail segments, several consistent patterns emerged that provide insight into the complex dynamics of snake-like locomotion. The following analysis categorizes these observations into specific aspects of the robot's movement behavior, highlighting key factors that influence performance and stability during operation.

\subsubsection{Differential Weight Distribution Effects}
A key observation across all configurations was the influence of the robot's weight distribution. The snake-like robot has a noticeably heavier head than the tail, creating an uneven friction distribution along its body. This weight imbalance resulted in the head maintaining better grip on the surface while the lighter tail exhibited greater slippage, particularly in configurations without additional friction elements.

The head's greater mass resulted in more consistent contact with the surface and higher friction, allowing it to serve as an anchor point during movement. In contrast, the tail section frequently displayed observable slippage during propulsive movements, reducing locomotion efficiency and directional stability.

\subsubsection{Lateral Undulation Performance}
Lateral undulation showed distinct movement characteristics across the different configurations, as illustrated in Figure~\ref{fig:lateral_undulation_analysis}, which presents the horizontal and vertical head and tail positions based on the tracking data.

\begin{figure}[H]
    \centering
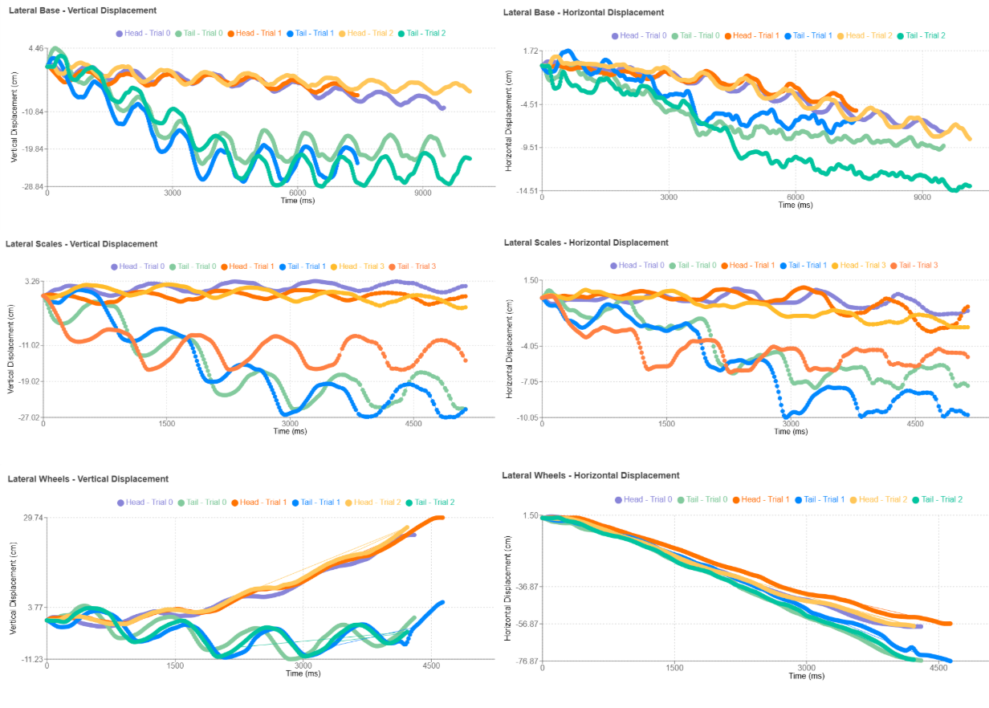
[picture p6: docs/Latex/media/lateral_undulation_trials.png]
    
    \caption{Head and tail trajectory patterns during lateral undulation for different configurations. Data generated from multiple trial runs using React visualization code.}
    \label{fig:lateral_undulation_analysis}
\end{figure}

With TPU scales attached, an interesting phenomenon was observed. The head remained in a relatively stationary position with minimal movement, functioning essentially as a pivot point. Meanwhile, the tail exhibited significant lateral slippage and movement. This differential between the stationary head and mobile tail resulted in the snake-like robot effectively rotating around its head position. The scales created such high friction at the head that it became anchored while the tail's movement generated rotational rather than forward motion.

The baseline configuration (without attachments) demonstrated a more distributed movement pattern. Without the additional friction element, the head also experienced slippage, though noticeably less compared to the tail. This allowed for more coordinated forward progression as both head and tail participated in the movement, albeit with the tail still showing greater lateral deviation due to its lighter weight. The reduced friction differential between head and tail in the baseline configuration resulted in less rotational movement and more linear progression.

The wheeled configuration demonstrated the most unified movement pattern during lateral undulation. The wheels created consistent rolling contact points that significantly reduced the slippage differential between head and tail. Both head and tail followed nearly parallel paths with minimal lateral deviation, resulting in a more direct forward progression. The wheels effectively compensated for the weight imbalance by providing uniform friction across the robot's body segments.

\subsubsection{Sidewinding Performance}
Sidewinding exhibited more complex movement patterns than initially anticipated. When the sidewinding algorithm was activated for forward progression, the robot moved sideways to the right. Interestingly, there was minimal difference in this behavior between the scaled and baseline configurations, suggesting that sidewinding is less dependent on surface friction compared to lateral undulation.

During this rightward sidewinding motion, the tail exhibited significantly more lateral movement than the head. This differential movement resulted in the tail generating a forward progression component while the head maintained a more stable position. The outcome was an arcing trajectory rather than the expected linear path.

When the sidewinding algorithm was executed in reverse, the robot moved to the left with a noticeably different pattern. In this direction, both head and tail showed more unified movement, resulting in a more consistent sideways displacement with less forward progression. This directional asymmetry suggested an underlying structural or algorithmic issue.

Further investigation of the robot's physical structure revealed a slight but significant design flaw. Along the chain of servo connections, a gradual tilt accumulates, resulting in the tail section having asymmetric ground contact. Specifically, one side of the tail maintains more consistent contact with the ground surface than the other. This structural asymmetry explains the different behavior patterns observed in rightward versus leftward sidewinding.

This asymmetric ground contact influenced the ground reaction forces experienced during sidewinding, creating the directional bias observed in the robot's movement. Figure~\ref{fig:sidewinding_analysis} illustrates these trajectory differences between rightward and leftward sidewinding patterns.

\begin{figure}[H]
    \centering
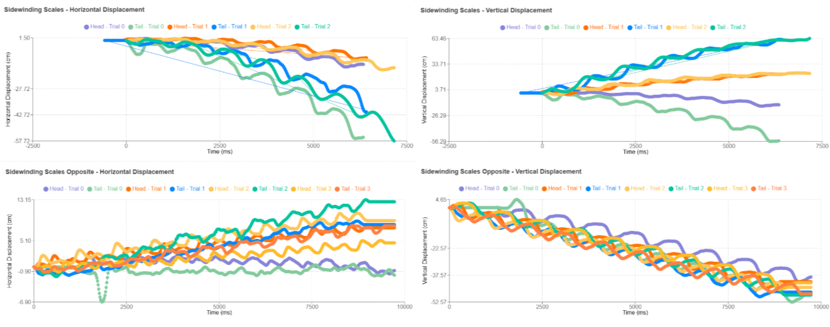
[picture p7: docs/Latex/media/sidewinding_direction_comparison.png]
    
    \caption{Head and tail trajectory paths during rightward and leftward sidewinding, showing asymmetric movement patterns due to structural tilt. Data compiled from multiple experimental trials and visualized using React-based graphing tools.}
    \label{fig:sidewinding_analysis}
\end{figure}

\subsubsection{Friction Enhancement and Movement Coordination}
A consistent finding across all locomotion patterns was that adding friction elements (either scales or wheels) unified the movement patterns between the head and tail sections. In both locomotion modes, slippage was observed more prominently in the baseline configuration without scales or wheels.

The addition of either scales or wheels served as a critical friction parameter that helped equalize the movement characteristics between the heavier, more stable head and the lighter, more slip-prone tail. This unification effect was particularly pronounced during directional changes, where the baseline configuration often showed the tail "whipping" or sliding unpredictably while the head maintained its intended path.

Repeated trials confirmed this pattern with minimal deviations, suggesting that friction enhancement is a fundamental factor in achieving coordinated snake-like locomotion on smooth surfaces like laminate flooring. The tracking data of head and tail positions on both vertical and horizontal axes consistently demonstrated that reducing the friction differential between body segments leads to more predictable and efficient movement patterns.

\section{Energy Consumption Analysis}
Power consumption was measured using the ACS712 current sensor integrated into the robot's power system. The ESP32 microcontroller recorded current measurements during operation, providing insights into the energy requirements of different locomotion strategies and configurations. Data was collected across multiple test runs for each locomotion mode and stored in CSV format for subsequent analysis.

\subsection{Experimental Setup and Data Collection}
For each locomotion mode, multiple experimental runs were conducted to ensure reproducibility and reliability of the measurements. Each experiment was time-synchronized, allowing for direct comparison between runs. The following locomotion modes were tested:

\begin{itemize}
    \item Idle Mode (robot powered but static)
    \item Lateral Undulation with Wheels
    \item Lateral Undulation with Scales
    \item Lateral Undulation Base (without additional locomotion aids)
    \item Sidewinding Base
    \item Sidewinding with Scales
\end{itemize}

Current measurements were recorded at a sampling rate of approximately 10 Hz, providing sufficient temporal resolution to capture transient effects during motion cycles.

\subsection{Idle Mode Current Draw}
The idle mode represents the baseline power consumption when the robot is powered but remaining stationary, with servos energized but not in motion.

\begin{figure}[H]
    \centering
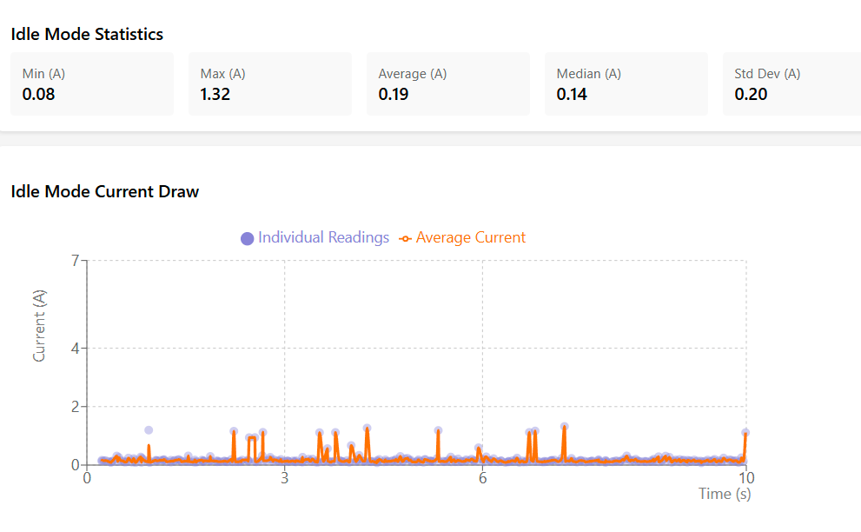
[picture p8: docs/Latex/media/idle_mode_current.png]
    
    \caption{Current draw in idle mode across multiple experimental runs. The scatter plot shows individual measurements, while the solid line represents the average current.}
    \label{fig:idle_current}
\end{figure}

Analysis of the idle mode data revealed:
\begin{itemize}
    \item Current Range: 0.08--1.32 A
    \item Average Current: 0.19 A
    \item Median Current: 0.14 A
    \item Standard Deviation: 0.20 A
\end{itemize}

Even in idle mode, the current draw exhibited periodic fluctuations, likely due to the servos maintaining position against gravitational forces or small mechanical disturbances. These small peaks correspond to the servo motors drawing additional current to maintain their commanded positions.

\subsection{Lateral Undulation Current Analysis}
Three configurations of lateral undulation were tested: with wheels, with scales, and the base configuration. These configurations allow us to quantify the effect of different friction conditions on power consumption.

\begin{figure}[H]
    \centering
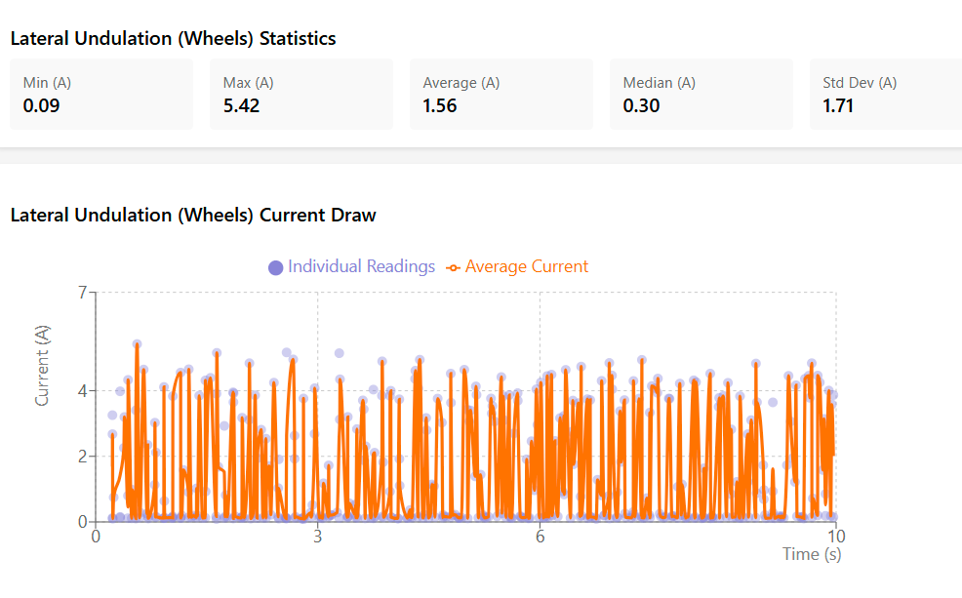
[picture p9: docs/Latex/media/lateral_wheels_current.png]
    
    \caption{Current draw during lateral undulation with wheels. The scatter plot shows individual measurements across multiple runs, with the average current trend line overlaid.}
    \label{fig:lateral_wheels_current}
\end{figure}

\begin{figure}[H]
    \centering
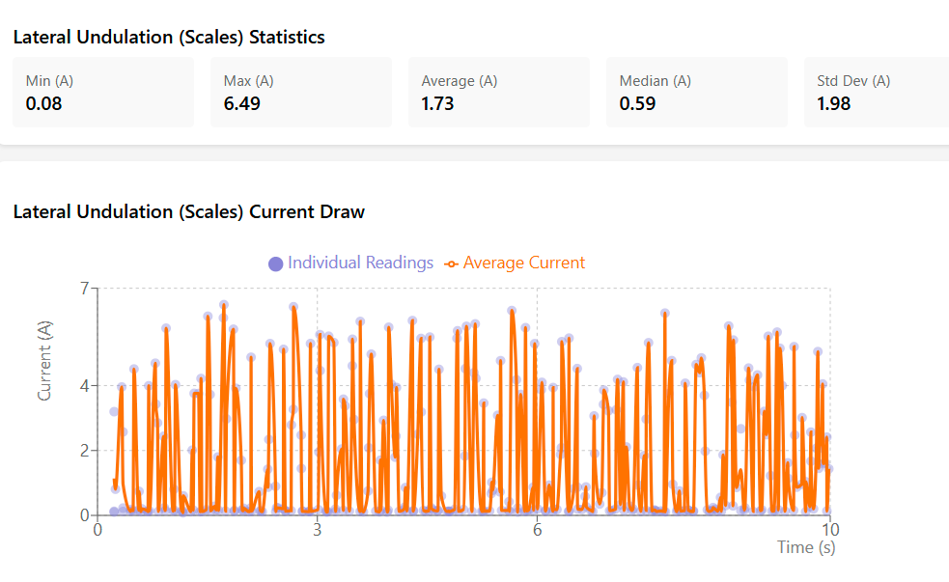
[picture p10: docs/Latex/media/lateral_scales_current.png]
    
    \caption{Current draw during lateral undulation with scales. The scatter plot shows individual measurements across multiple runs, with the average current trend line overlaid.}
    \label{fig:lateral_scales_current}
\end{figure}

\begin{figure}[H]
    \centering
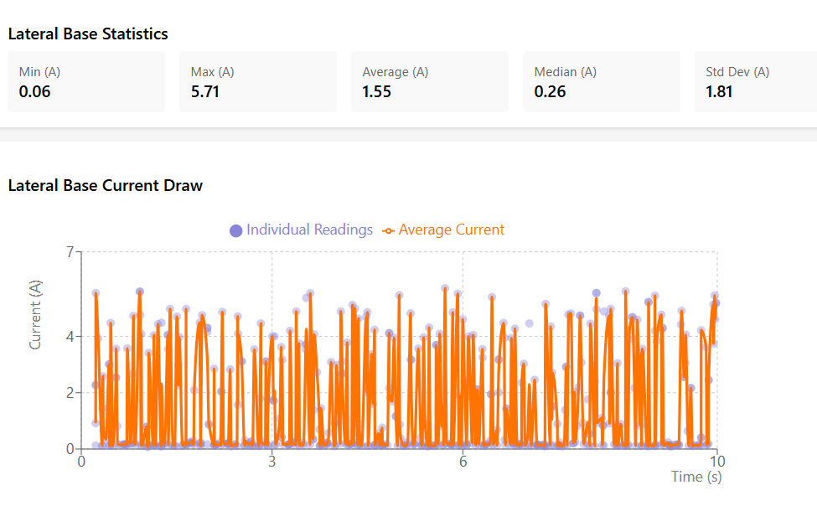
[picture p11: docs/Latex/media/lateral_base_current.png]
    
    \caption{Current draw during lateral undulation in base configuration (without additional locomotion aids). The scatter plot shows individual measurements across multiple runs, with the average current trend line overlaid.}
    \label{fig:lateral_base_current}
\end{figure}

Key statistics for lateral undulation modes:

\begin{table}[H]
    \centering
    \adjustbox{max width=\textwidth}{
    \begin{tabular}{|l|c|c|c|c|}
        \hline
        \textbf{Configuration} & \textbf{Current Range (A)} & \textbf{Average (A)} & \textbf{Median (A)} & \textbf{Std Dev (A)}\\
        \hline
        Lateral Base & 0.06--5.71 & 1.55 & 0.26 & 1.81 \\
        \hline
        Lateral Undulation (Wheels) & 0.09--5.42 & 1.56 & 0.30 & 1.71 \\
        \hline
        Lateral Undulation (Scales) & 0.08--6.49 & 1.73 & 0.59 & 1.98 \\
        \hline
    \end{tabular}
    }
    \caption{Current consumption statistics across different lateral undulation configurations.}
    \label{tab:lateral_current_measurements}
\end{table}

The data reveals several important findings:
\begin{itemize}
    \item Lateral undulation with scales shows the highest average current draw (1.73 A) among the lateral locomotion modes, approximately 11\% higher than with wheels.
    \item The higher median value for scales configuration (0.59 A vs 0.30 A for wheels) indicates that scales consistently require more power throughout the motion cycle.
    \item All configurations exhibit significant current spikes, with the scales configuration reaching the highest peaks (up to 6.49 A), likely during direction changes or when overcoming static friction.
    \item The larger standard deviation in the scales configuration (1.98 A) suggests more variable power requirements depending on the phase of the motion pattern.
\end{itemize}

\subsection{Sidewinding Current Analysis}
Sidewinding represents a more complex three-dimensional motion pattern that involves coordinated vertical and horizontal movements. Two configurations were tested: the base sidewinding pattern and sidewinding with scales.

\begin{figure}[H]
    \centering
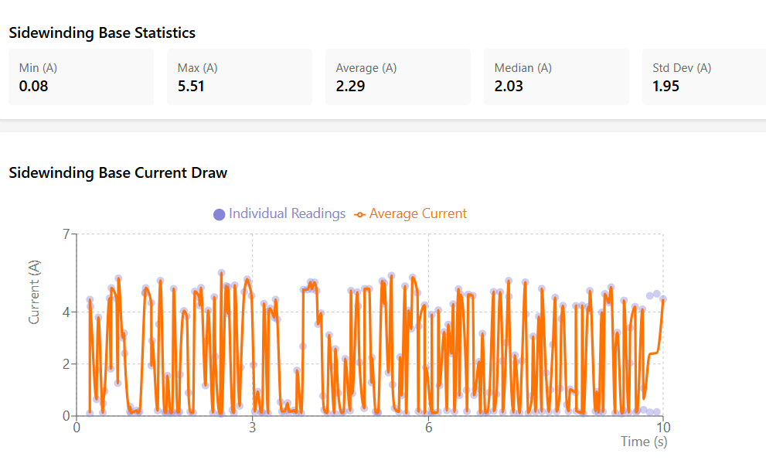
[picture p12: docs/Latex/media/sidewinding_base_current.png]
    
    \caption{Current draw during sidewinding in base configuration. The scatter plot shows individual measurements across multiple runs, with the average current trend line overlaid.}
    \label{fig:sidewinding_base_current}
\end{figure}

\begin{figure}[H]
    \centering
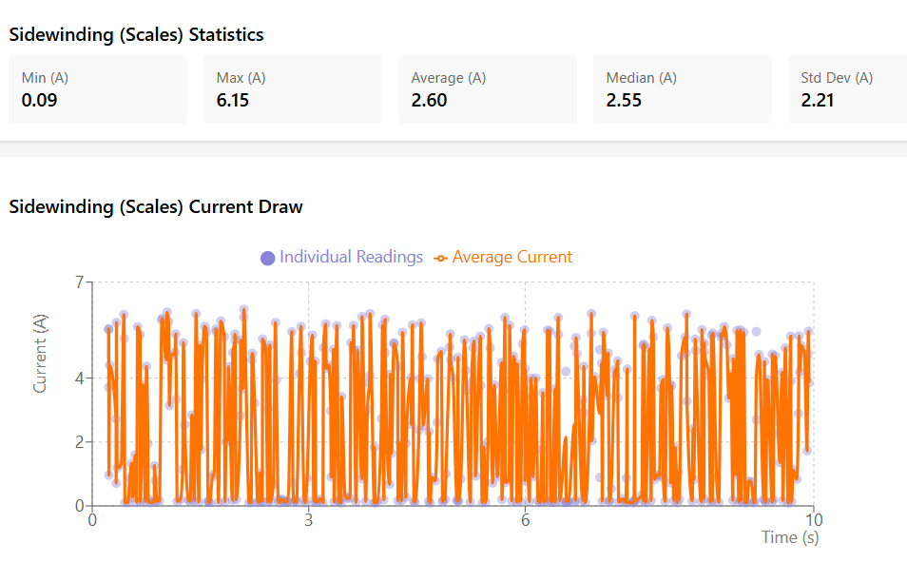
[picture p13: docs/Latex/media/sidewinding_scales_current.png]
    
    \caption{Current draw during sidewinding with scales. The scatter plot shows individual measurements across multiple runs, with the average current trend line overlaid.}
    \label{fig:sidewinding_scales_current}
\end{figure}

Key statistics for sidewinding modes:

\begin{table}[H]
    \centering
    \adjustbox{max width=\textwidth}{
    \begin{tabular}{|l|c|c|c|c|}
        \hline
        \textbf{Configuration} & \textbf{Current Range (A)} & \textbf{Average (A)} & \textbf{Median (A)} & \textbf{Std Dev (A)}\\
        \hline
        Sidewinding Base & 0.08--5.51 & 2.29 & 2.03 & 1.95 \\
        \hline
        Sidewinding (Scales) & 0.09--6.15 & 2.60 & 2.55 & 2.21 \\
        \hline
    \end{tabular}
    }
    \caption{Current consumption statistics across different sidewinding configurations.}
    \label{tab:sidewinding_current_measurements}
\end{table}

Analysis of the sidewinding data reveals:
\begin{itemize}
    \item Both sidewinding configurations show significantly higher average and median current draw compared to lateral undulation modes, with sidewinding with scales consuming the most power overall (2.60 A average).
    \item The close values between median and average in sidewinding modes (especially with scales) indicates a more consistent power draw throughout the motion cycle, unlike the lateral modes which showed larger differences between median and average.
    \item Peak current values during sidewinding with scales reached 6.15 A, indicating substantial instantaneous power demands.
    \item The high standard deviation in both configurations (1.95-2.21 A) reflects the complex nature of the motion pattern, with significant variations in power requirements during different phases of the movement.
\end{itemize}

\subsection{Comparative Analysis of Locomotion Modes}
To better understand the relative energy efficiency of different locomotion strategies, a comparative analysis was performed across all tested configurations.

\begin{figure}[H]
    \centering
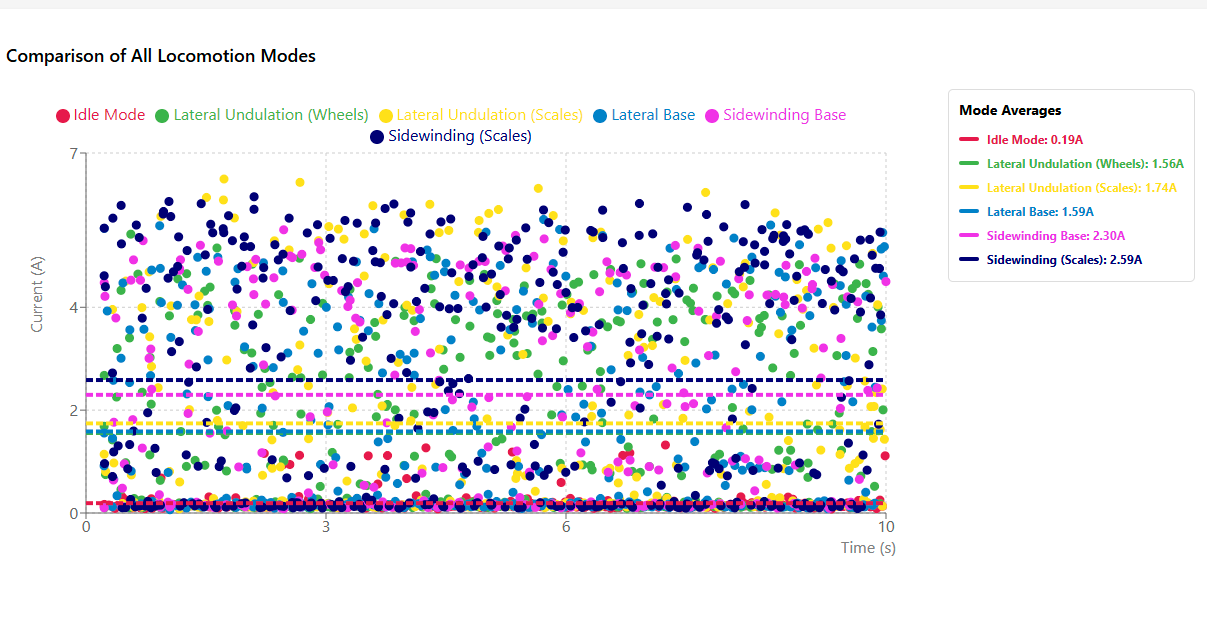
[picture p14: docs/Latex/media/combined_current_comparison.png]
    
    \caption{Comparison of average current draw across all tested locomotion modes over a 10-second period. This visualization highlights the relative energy requirements of different motion strategies and configurations.}
    \label{fig:combined_current}
\end{figure}

\begin{table}[H]
    \centering
    \adjustbox{max width=\textwidth}{
    \begin{tabular}{|l|c|c|c|c|}
        \hline
        \textbf{Locomotion Mode} & \textbf{Current Range (A)} & \textbf{Average (A)} & \textbf{Median (A)} & \textbf{Std Dev (A)} \\
        \hline
        Idle Mode & 0.08--1.32 & 0.19 & 0.14 & 0.20 \\
        \hline
        Lateral Undulation (Wheels) & 0.09--5.42 & 1.56 & 0.30 & 1.71 \\
        \hline
        Lateral Undulation (Scales) & 0.08--6.49 & 1.73 & 0.59 & 1.98 \\
        \hline
        Lateral Base & 0.06--5.71 & 1.55 & 0.26 & 1.81 \\
        \hline
        Sidewinding Base & 0.08--5.51 & 2.29 & 2.03 & 1.95 \\
        \hline
        Sidewinding (Scales) & 0.09--6.15 & 2.60 & 2.55 & 2.21 \\
        \hline
    \end{tabular}
    }
    \caption{Comprehensive current consumption statistics across all locomotion modes.}
    \label{tab:current_measurements_complete}
\end{table}

Key comparative findings:
\begin{itemize}
    \item \textbf{Idle vs. Active Motion:} Any form of locomotion increases power consumption dramatically, with lateral undulation requiring approximately 8.2 times more power than idle mode (1.56-1.73 A vs. 0.19 A), and sidewinding requiring 12-13.7 times more power (2.29-2.60 A vs. 0.19 A).
    
    \item \textbf{Lateral Undulation Configurations:} The three lateral undulation configurations showed similar average current draw, with the scales configuration consuming only marginally more power (1.73 A) than the wheels (1.56 A) and base (1.55 A) configurations. However, the median values reveal that the scales configuration (0.59 A) maintains a higher baseline current throughout the motion cycle compared to the other configurations (0.26-0.30 A).
    
    \item \textbf{Sidewinding vs. Lateral Undulation:} Sidewinding motion patterns consume substantially more power than lateral undulation, with sidewinding with scales requiring approximately 50\% more energy than lateral undulation with scales (2.60 A vs. 1.73 A). This confirms that three-dimensional motion patterns involving both horizontal and vertical servo activation are significantly more power-intensive.
    
    \item \textbf{Effect of Scales:} The addition of scales consistently increased power consumption across both motion patterns, with a more pronounced effect in sidewinding (13.5\% increase) compared to lateral undulation (11\% increase). This highlights the impact of increased friction on energy requirements.
    
    \item \textbf{Peak Current Analysis:} All locomotion modes exhibited significant current spikes, with the highest peaks occurring in the lateral undulation with scales configuration (6.49 A). These spikes typically occurred during direction changes or when overcoming initial static friction. The high variability in current draw (as indicated by the large standard deviations) suggests opportunities for energy optimization by smoothing acceleration and deceleration profiles.
    
    \item \textbf{Consistency of Motion:} Sidewinding modes showed higher median values closer to their averages, indicating more consistent power draw throughout the motion cycle. In contrast, lateral undulation modes showed much lower median values compared to their averages, suggesting more intermittent high-current phases separated by lower-power periods.
\end{itemize}

%//////////////////
%//////////////////
%chapter 5
%//////////////////
%//////////////////
\chapter{Conclusion and Future Work}
\label{ch:conclusion}

This thesis has presented the development, implementation, and experimental evaluation of a neurobiologically inspired control system for a snake-like robot. The primary objectives were to (1) design and 3D-print a modular mechanical structure using Onshape, (2) integrate an ESP32 microcontroller with ten servo motors to achieve biomimetic locomotion, and (3) implement Central Pattern Generators (CPGs) in Arduino IDE to realize biologically-inspired movement patterns. The experimental results demonstrate that this approach can produce effective serpentine locomotion while maintaining relative simplicity in hardware and software design.

\section{Summary of Contributions}
\label{sec:contribution}

The main contribution of this work is the successful implementation of a biomimetic snake robot utilizing neurobiologically inspired control principles. A segment-based design was created in Onshape to emulate serpentine motion, enabling modular, repeatable segments that could be easily 3D-printed. The structure successfully balanced weight distribution concerns while providing sufficient robustness for extended testing. Three distinct configurations were developed and tested: a baseline version, one with TPU-printed passive scales representing a biomimetic approach, and one with wheels on each segment.

The hardware system was built around an ESP32 microcontroller serving as the central controller, interfacing with ten servo motors arranged in alternating horizontal and vertical orientations. This arrangement allowed for both lateral undulation and sidewinding motion patterns. The system was complemented with an ACS712 current sensor for power consumption analysis and a web interface for real-time control and data collection, enabling comprehensive performance evaluation during experimentation.

Two primary locomotion patterns were successfully implemented through CPG-inspired algorithms: lateral undulation and sidewinding. These algorithms generated sinusoidal wave patterns with configurable parameters including amplitude, frequency, and phase offset, closely mimicking biological snake movement. The implemented control system allowed for real-time parameter adjustment, enabling exploration of different movement characteristics and their impact on locomotion performance.

Extensive experimental testing was conducted using a structured grid environment and motion tracking software (Kinovea) to analyze the robot's movement patterns. The experiments yielded quantitative data on movement characteristics across different configurations and locomotion patterns, as well as detailed energy consumption measurements for all tested modes. This comprehensive analysis provided valuable insights into the complex relationships between mechanical configuration, control parameters, and resulting motion characteristics.

\section{Key Findings}
\label{sec:findings}

This section synthesizes the primary insights gained from the systematic evaluation of the snake robot's performance across multiple configurations and locomotion patterns.

\subsection{Locomotion Performance}
\label{subsec:loco_findings}

The experimental evaluation revealed that different robot configurations exhibited distinct movement characteristics that significantly impacted locomotion performance. The wheeled configuration provided the most uniform movement during lateral undulation, with minimal lateral deviation and the most direct forward progression. In contrast, the TPU scales configuration created such high friction at the head that it became anchored while the tail's movement generated rotational rather than forward motion.

A key observation across all configurations was the influence of the robot's uneven weight distribution. The snake-like robot had a noticeably heavier head than tail, creating an uneven friction distribution along its body. This weight imbalance resulted in the head maintaining better grip on the surface while the lighter tail exhibited greater slippage, particularly in configurations without additional friction elements. The head's greater mass resulted in more consistent contact with the surface and higher friction, allowing it to serve as an anchor point during movement. In contrast, the tail section frequently displayed observable slippage during propulsive movements, reducing locomotion efficiency and directional stability.

Sidewinding exhibited more complex movement patterns than initially anticipated. When the sidewinding algorithm was activated for forward progression, the robot moved sideways to the right with minimal difference in behavior between the scaled and baseline configurations. This suggested that sidewinding is less dependent on surface friction compared to lateral undulation. Interestingly, rightward sidewinding produced a slight arcing trajectory rather than the expected linear path, while leftward sidewinding showed more unified movement with consistent sideways displacement and less forward progression.

Further investigation revealed that a slight but significant structural asymmetry in the robot's design—specifically a gradual tilt accumulation along the servo chain—affected ground contact distribution and created directional bias during sidewinding movements. This asymmetric ground contact influenced the ground reaction forces experienced during sidewinding, explaining the directional bias observed in the robot's movement.

A consistent finding across all locomotion patterns was that adding friction elements (wheels) significantly unified the movement patterns between the head and tail sections. This unification effect was particularly pronounced during directional changes, where the baseline configuration often showed the tail "whipping" or sliding unpredictably while the head maintained its intended path.

\subsection{Energy Consumption}
\label{subsec:energy_findings}

The energy consumption analysis revealed significant differences between locomotion modes and configurations. Sidewinding movements required substantially more power than lateral undulation, with sidewinding with scales requiring approximately 50\% more energy than lateral undulation with scales (2.60 A vs. 1.73 A average current draw). This confirmed that three-dimensional motion patterns involving both horizontal and vertical servo activation are significantly more power-intensive.

The addition of scales consistently increased power consumption across both motion patterns, with a more pronounced effect in sidewinding (13.5\% increase) compared to lateral undulation (11\% increase). This highlighted the impact of increased friction on energy requirements. The three lateral undulation configurations showed similar average current draw, with the scales configuration consuming only marginally more power than the wheels and base configurations. However, the median values revealed that the scales configuration maintained a higher baseline current throughout the motion cycle compared to the other configurations.

\section{Limitations of the Current Implementation}
\label{sec:limitations}

Despite the promising results, several limitations were encountered during the experimental phase. One of the primary hardware constraints was the use of SG90 servos, which, while lightweight and compact, provided limited torque. This reduced the robot's ability to execute high-amplitude motions effectively and constrained its overall force output. Additionally, the system was powered by a single 18650 battery, which not only restricted the operating time but also limited the available power supply for the servos. As a result, maintaining consistent motion and torque output over extended periods proved challenging.

Another constraint arose from the ESP32's limited number of GPIO pins, which imposed a restriction on the number of servos that could be controlled simultaneously, limiting the potential for further expansion.Also the structural tilt along the robot body affected movement symmetry and ground contact distribution, creating the directional bias observed during sidewinding locomotion.

Beyond hardware limitations, several challenges were noted in software and control. The web-based control system, while functional, suffered from occasional WiFi interruptions, especially in environments with multiple overlapping networks, which impacted real-time responsiveness. Additionally, the ESP32 had to manage multiple tasks simultaneously, including web server communication, motion generation, and data logging. Under high processing loads, occasional slowdowns were observed, affecting the fluidity of motion execution.

Perhaps the most significant control limitation was the lack of direct feedback in the system. Operating in an open-loop configuration meant that there was no real-time positional or orientation feedback, making it difficult to dynamically adjust movements or compensate for external disturbances. This limited the robot's ability to adapt to changing environmental conditions or unexpected obstacles during locomotion.

\section{Future Improvements}
\label{sec:futureWork}
Based on the experimental results and performance analysis, several potential enhancements have been identified that could address the limitations observed in the current snake robot prototype. These improvements target specific aspects of the robot's design and functionality to enhance its locomotion capabilities.

\subsection{Enhanced Mechanical Design}
\label{subsec:mechanical_improvements}

Future iterations of the snake robot design should address the uneven weight distribution that causes differential friction between head and tail sections. A more balanced weight arrangement would promote more uniform movement and reduce unintended rotational tendencies during lateral undulation. This could be achieved through careful redistribution of electronic components or the strategic addition of counterweights in the tail section. Simultaneously, improvements in mechanical design should focus on eliminating the gradual tilt accumulation along the servo chain that created directional bias in sidewinding motion. More precise alignment mechanisms and structural reinforcement could mitigate this issue, ensuring more symmetrical movement in both directions.
Selective reinforcement at high-stress connection points could enhance longevity without significantly increasing weight.
Developing interchangeable friction elements would further enhance the robot's versatility across varied terrains. The current experimental results clearly demonstrated that different friction mechanisms (scales, wheels, or the baseline configuration) offer distinct advantages depending on the desired movement pattern and surface characteristics. A modular design allowing quick interchange between these configurations would enable rapid adaptation to changing environmental conditions and locomotion requirements.

\subsection{Power System Enhancements}
\label{subsec:power_improvements}

The energy consumption analysis highlighted several opportunities for power system improvements. Upgrading to higher capacity batteries or implementing a dual-battery system would extend operational runtime, particularly for power-intensive movements like sidewinding. The current consumption data indicates that sidewinding requires approximately 50\% more energy than lateral undulation, suggesting that power capacity is a critical factor for robots intended to utilize this movement pattern extensively.

Replacing the SG90 servos with higher-torque, more energy-efficient alternatives would improve motion capability while potentially reducing peak current demands through better mechanical efficiency. More powerful servos would also enable more reliable execution of high-amplitude movements, potentially improving locomotion effectiveness on challenging terrains. The current spikes observed during motion transitions suggest that implementing intelligent power management that dynamically adjusts servo parameters based on battery state and motion requirements could significantly extend operational duration.
Developing smoother acceleration and deceleration profiles could reduce the current spikes observed during transitions, potentially lowering peak power demands and improving overall efficiency. 

\subsection{Low-Latency Control with ESP-NOW}
\label{subsec:esp_now_control}

While the web interface provided a functional control mechanism for the snake robot, it introduced noticeable latency due to the HTTP request processing and potential WiFi network congestion. Future iterations of the system could benefit significantly from implementing ESP-NOW, a peer-to-peer protocol developed by Espressif that offers lower latency and reduced power consumption compared to traditional WiFi connections.

ESP-NOW would enable the development of a dedicated handheld controller using another ESP32 board, creating a direct communication channel with the snake robot. This approach offers several key advantages: response times could be reduced from hundreds of milliseconds to less than 10ms, providing near real-time control that would allow for more precise manipulation of the robot's movements. The protocol's lightweight nature would reduce the processing overhead on the ESP32 controller, potentially freeing computational resources for more complex locomotion algorithms or sensor processing.
Additionally, ESP-NOW's simplified connection mechanism eliminates the need for the snake robot to maintain an access point and web server, reducing power consumption and extending battery life. The protocol also offers greater operational range compared to the current web interface approach, potentially allowing control from distances of up to 400 meters in open areas. Implementation would require developing a custom controller with joysticks, buttons, and potentially a small display to provide feedback on robot parameters such as battery status and current locomotion mode.
For educational and research applications, this system could be extended to allow seamless switching between autonomous operation (utilizing the CPG algorithms) and direct operator control.

\subsection{Advanced Control Algorithms}
\label{subsec:control_improvements}

The open-loop control system used in the current implementation showed promising results but lacked the ability to adapt to changing conditions or compensate for structural asymmetries. Integrating sensors such as IMUs (Inertial Measurement Units) would enable closed-loop control, allowing the robot to adapt its movement based on real-time feedback about its position, orientation, and movement characteristics. This feedback could be used to dynamically adjust CPG parameters to maintain desired movement trajectories despite environmental disturbances or mechanical asymmetries.

Machine learning algorithms could be implemented to dynamically adjust CPG parameters (frequency, amplitude, phase offset) based on environmental conditions and performance feedback. This adaptive approach could optimize locomotion efficiency across different terrains by automatically selecting the most effective parameter combinations based on sensed conditions and movement outcomes. The system could learn from experience, progressively refining its parameter selection to improve performance over time.

\subsection{Extended Applications}
\label{subsec:applications}

The modular snake-like robot design developed in this thesis has potential applications beyond the experimental context. With further development, the system could be adapted for confined-space exploration and search and rescue operations, leveraging its ability to navigate narrow passages inaccessible to traditional robots. The snake's flexible body configuration and ability to execute three-dimensional movement patterns make it well-suited for traversing complex environments with limited clearance.

The design could also be adapted for pipeline or structural inspection tasks by integrating appropriate sensors and enhancing the robot's ability to navigate vertical surfaces. The potential for sidewinding movement on inclined surfaces, combined with the robot's elongated body, makes it a promising platform for industrial inspection applications where access is limited and maneuverability is essential.

In educational contexts, simplified versions of the system could serve as platforms for teaching principles of biomimetic robotics, control systems, and 3D design and fabrication. The accessible hardware platform (ESP32) and software environment (Arduino IDE) make the system approachable for educational purposes, while the clear relationship between biological principles and robotic implementation provides valuable learning opportunities.

Exploring the potential for multiple snake robots to coordinate their movements could lead to novel applications in distributed sensing or collaborative manipulation tasks. For example, a group of snake robots could form temporary structures or cooperatively transport objects by leveraging their flexible bodies and varied movement capabilities.

\section{Concluding Remarks}
\label{sec:concludingRemarks}

This thesis has demonstrated that a neurobiologically inspired approach to snake robot design and control can produce effective biomimetic locomotion using accessible hardware and software platforms. The detailed experimental analysis has provided valuable insights into the complex relationships between mechanical configuration, control parameters, and movement characteristics, highlighting both the potential and challenges of snake-like robotic systems.

The findings underscore the importance of considering weight distribution, ground contact dynamics, and energy efficiency in biomimetic robot design. The significant differences observed between locomotion patterns and configurations emphasize the need for adaptive, context-sensitive control approaches that can leverage the unique advantages of different movement strategies. The energy consumption analysis revealed important trade-offs between movement capability and operational duration, providing a foundation for future optimization efforts.

While the current implementation has certain limitations in terms of hardware capabilities and control sophistication, it provides a solid foundation for future research and development. The modular design approach, combined with the accessible ESP32 platform and Arduino IDE environment, creates a flexible experimental platform that can evolve to address increasingly complex challenges in biomimetic robotics.

As this field continues to advance, the integration of more sophisticated sensing, adaptive control algorithms, and optimized mechanical designs will push the boundaries of what snake-like robots can achieve. These systems hold significant promise for applications ranging from search and rescue operations to industrial inspection where their unique locomotion capabilities provide advantages over traditional wheeled or legged robots.

The neurobiological principles that inspired this work remain a rich source of insights for future robotic systems, highlighting how the elegant solutions evolved in biological organisms can inform the development of more adaptive, efficient, and versatile robotic technologies. By continuing to draw inspiration from nature while leveraging advances in materials, sensors, and computational capabilities, we can develop increasingly sophisticated biomimetic robots that combine the best aspects of biological and engineered systems.

% Appendices 
\appendix
%//////////////////////////////////////
%//////////////////////////////////////
%//////////////////////////////////////
%//////////////////////////////////////
%//////////////////////////////////////
\chapter{Hardware Specifications}
\section{Mechanical Design}
\subsection{3D Printed Components}

The snake robot is constructed from a variety of meticulously designed 3D-printed components, each engineered for structural integrity, modularity, and optimal functionality. All parts are 3D printed using PETG, PLA, PLA+, and TPU filaments, with tailored print settings that balance detail, strength, and weight.

\FloatBarrier
\subsubsection{Head Assembly}
The head assembly is divided into two primary sections: the \textbf{top-head} and the \textbf{bottom-head}. Together, they not only secure critical sensors and electronics but also enhance the aesthetic and structural characteristics of the robot. Key attributes include:
\begin{itemize}
    \item \textbf{Material:} PETG
    \item \textbf{Print Settings:} 0.2\,mm layer height with 30\% gyroid infill
    \item \textbf{Design Features:}
    \begin{itemize}
        \item Reinforced mounting slots for secure sensor and electronics placement
        \item A structured surface that blends visual appeal with mechanical strength
    \end{itemize}
\end{itemize}

\begin{figure}[H]
\centering
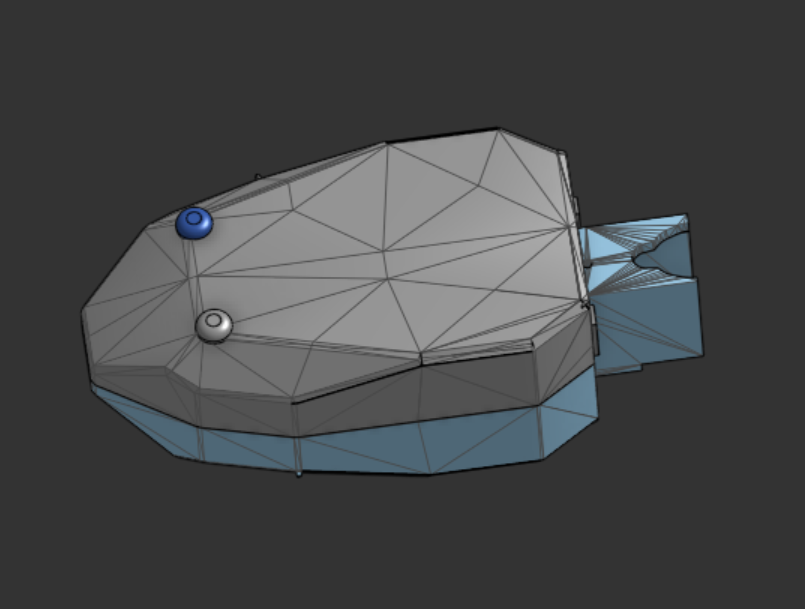
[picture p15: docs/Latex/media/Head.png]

\caption{Complete head assembly}
\par\vspace{4 mm}
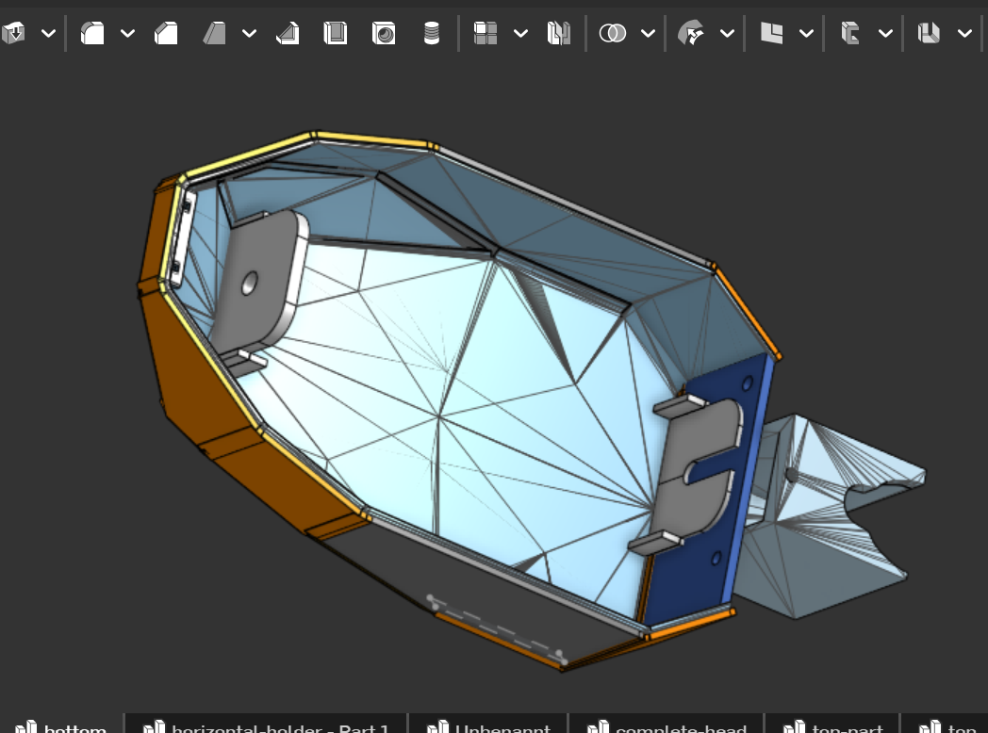
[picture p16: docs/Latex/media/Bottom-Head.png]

\caption{Bottom head assembly}
\par\vspace{4 mm}
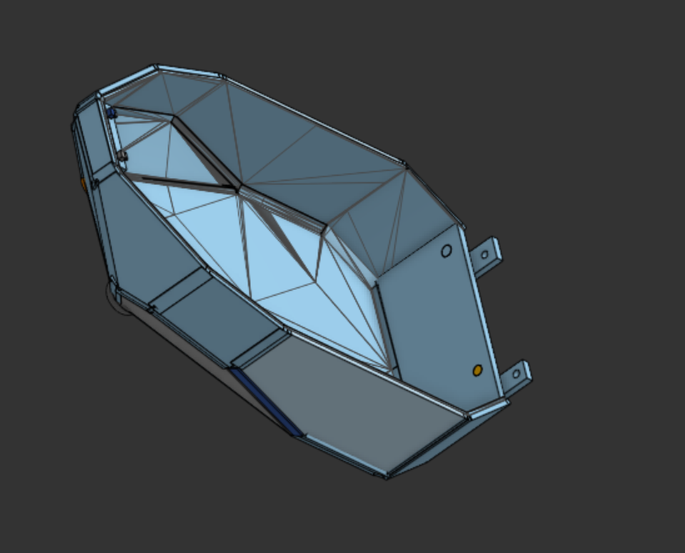
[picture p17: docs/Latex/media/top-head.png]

\caption{Combined view of the top and bottom head sections}
\end{figure}

\FloatBarrier
\subsubsection{Tail Structure}
The tail serves as a critical connector between the main body and the rear stabilizers, enabling controlled movement. Its design emphasizes both functionality and ease of integration:
\begin{itemize}
    \item \textbf{Material:} PETG
    \item \textbf{Print Settings:} 0.2\,mm layer height with 30\% infill
    \item \textbf{Key Features:}
    \begin{itemize}
        \item Reinforced mounting points designed for servo attachment
        \item Aesthetical rattlesnake tail design
    \end{itemize}
\end{itemize}

\begin{figure}[H]
\centering
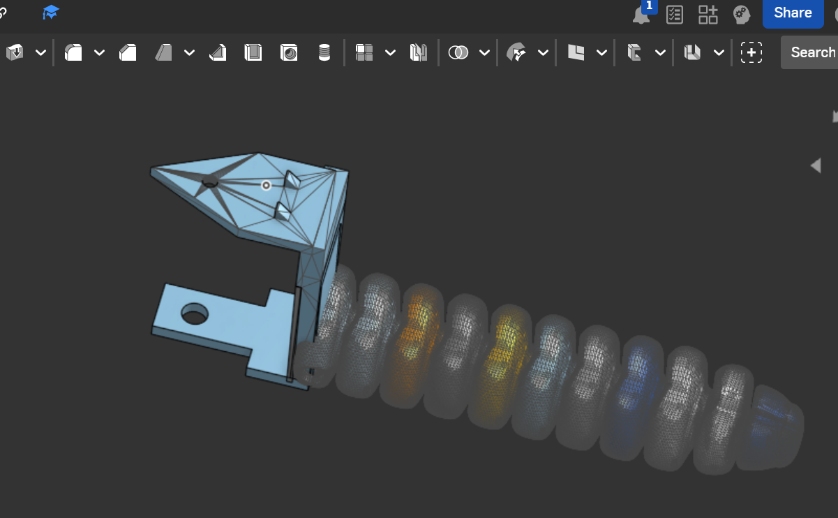
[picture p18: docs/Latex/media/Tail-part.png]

\caption{Tail structure assembly}
\end{figure}

\FloatBarrier
\subsubsection{Scales for Friction Optimization}
To enhance traction and optimize friction during movement, the robot incorporates an array of overlapping scales. These components are engineered for both flexibility and durability:
\begin{itemize}
    \item \textbf{Material:} TPU
    \item \textbf{Print Settings:} 0.1\,mm layer height to capture fine details
    \item \textbf{Design Characteristics:}
    \begin{itemize}
        \item Lightweight construction without compromising strength
        \item Flexible attachment points to adapt during motion
        \item A textured surface optimized for improved traction
    \end{itemize}
\end{itemize}

\begin{figure}[H]
\centering
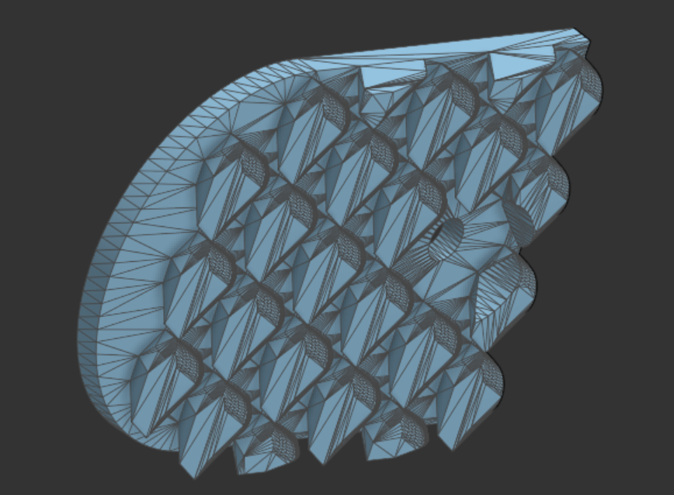
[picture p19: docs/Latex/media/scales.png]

\caption{3D printed scales for enhanced movement}
\end{figure}

\FloatBarrier
\subsubsection{Servo Holders}
Servo holders are integral to the robot's actuation system, providing secure and versatile mounting options for the servos. Two configurations are used:
\begin{itemize}
    \item \textbf{Material:} PETG
    \item \textbf{Print Settings:} 0.2\,mm layer height with 30\% infill for maximum strength
    \item \textbf{Features:}
    \begin{itemize}
        \item A snap-fit design that simplifies installation and removal
        \item Screw holes ensuring a stable and secure mounting
    \end{itemize}
\end{itemize}

\begin{figure}[H]
\centering
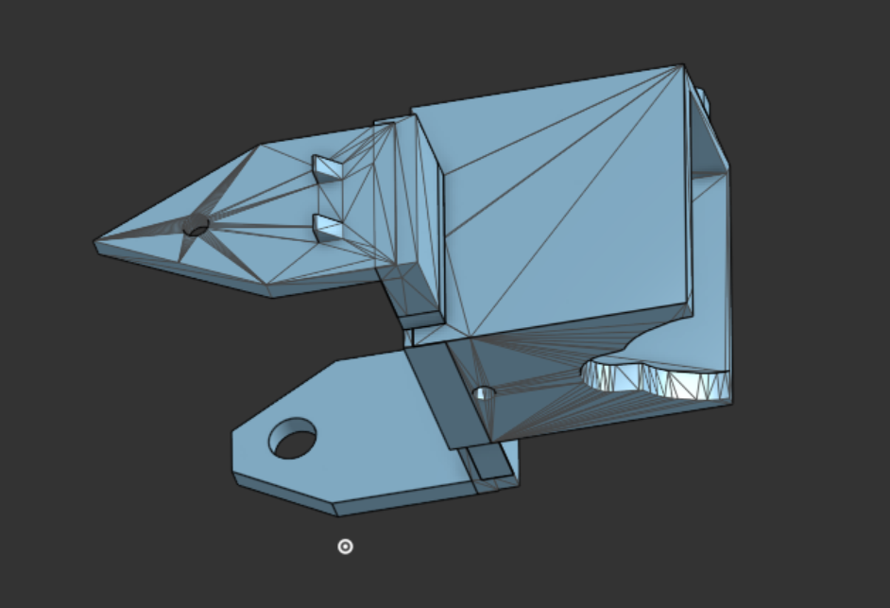
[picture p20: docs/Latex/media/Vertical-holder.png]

\caption{Vertical servo holder}
\par\vspace{4 mm}
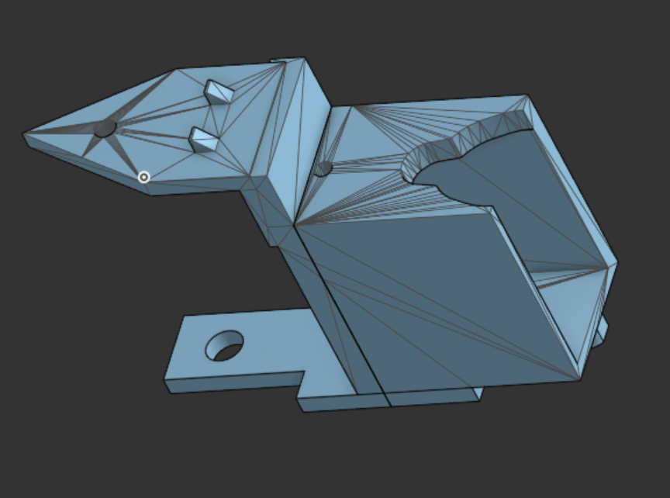
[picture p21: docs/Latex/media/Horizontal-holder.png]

\caption{Horizontal servo holder}
\end{figure}

\FloatBarrier
\subsubsection{Wheelbase, Wheel, and Tire}
A robust locomotion system is realized through the integration of a wheelbase, wheels, and tires:
\begin{itemize}
    \item \textbf{Wheelbase:} Positioned beneath the main body segments, each unit supports two small wheels to stabilize movement.
\end{itemize}

\begin{figure}[H]
\centering
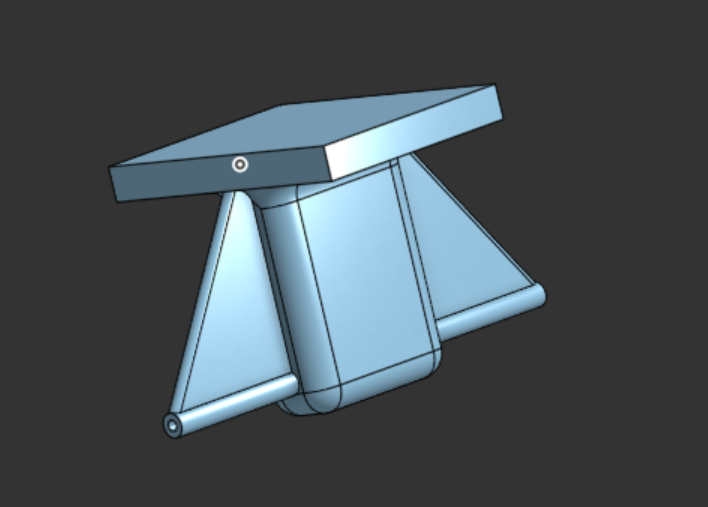
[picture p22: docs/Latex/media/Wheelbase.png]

\caption{Wheelbase assembly}
\end{figure}

\begin{itemize}
    \item \textbf{Wheel:} Engineered for smooth rotation and effective support.
\end{itemize}
\begin{itemize}
    \item \textbf{Tire:} Designed to provide optimal traction and cushioning during locomotion.
\end{itemize}

\begin{figure}[H]
\centering
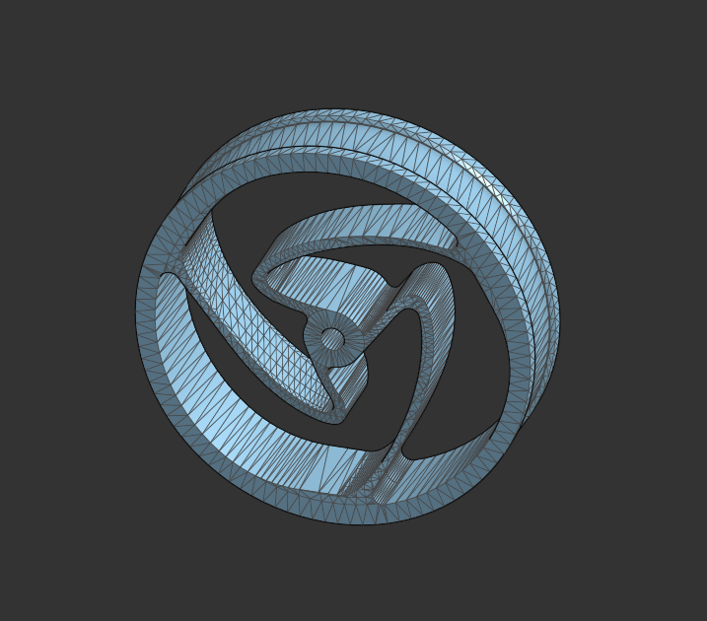
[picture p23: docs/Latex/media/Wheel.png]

\caption{Wheel component}
\end{figure}
\begin{figure}[H]
\centering
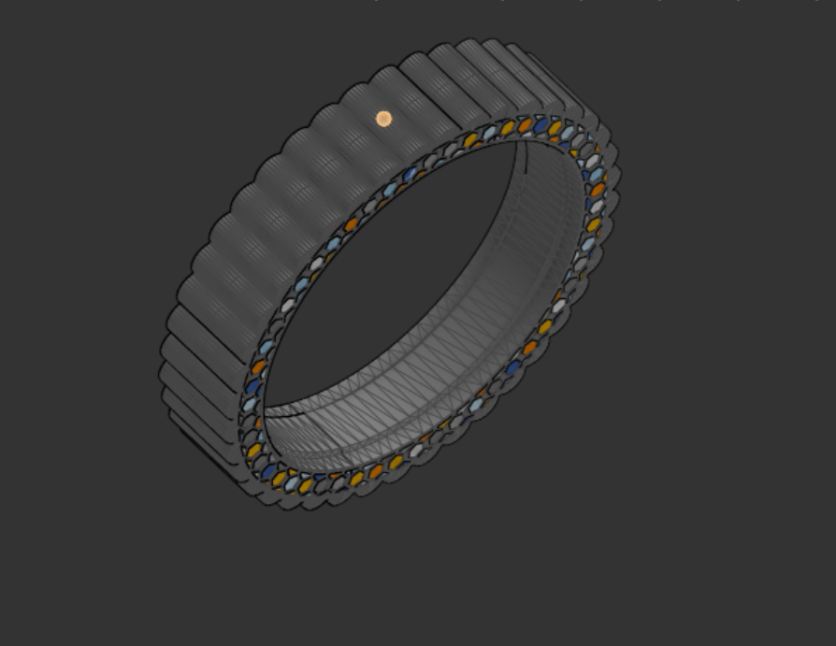
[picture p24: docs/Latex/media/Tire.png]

\caption{Tire component}
\end{figure}

\section{Electronic Components}
\subsection{Microcontroller Specifications}
\begin{itemize}
\item ESP32-WROOM-32 Development Board:
\begin{itemize}
\item Dual-core Xtensa LX6 microprocessor
\item Operating frequency up to 240 MHz
\item 520 KB SRAM
\item 4 MB Flash memory
\item Integrated WiFi 802.11 b/g/n
\item Bluetooth 4.2 support
\item Operating voltage: 3.3V
\item 34x programmable GPIO pins
\end{itemize}
\end{itemize}
\subsection{Servo Motor Details}
\begin{table}[H]
\centering
\begin{tabular}{|l|l|}
\hline
\textbf{Parameter} & \textbf{Value} \\
\hline
Model & SG90 \\
Operating Voltage & 4.8\,V -- 6.0\,V \\
Stall Torque (4.8\,V) & $\approx$1.5\,kg$\cdot$cm \\
Operating Speed (4.8\,V) & 0.12\,sec/60$^{\circ}$ \\
Operating Angle & 180$^{\circ}\,\pm\,5^{\circ}$ \\
Pulse Width Range & 500--2400\,$\mu$s \\
Direction & Bi-directional (CW/CCW) \\
Gear Type & Plastic Gears \\
Weight & 9\,g \\
Dimensions & 22.8\,$\times$\,12.2\,$\times$\,28.5\,mm \\
\hline
\end{tabular}
\caption{SG90 servo motor specifications.}
\end{table}

\subsection{Power System}
\begin{itemize}
    \item \textbf{Battery:}
    \begin{itemize}
        \item \textit{Type}: Single 18650 Li-ion cell
        \item \textit{Voltage}: 3.7\,V nominal (4.2\,V max)
        \item \textit{Capacity}: (varies by cell, e.g., 2200\,mAh)
        \item \textit{Weight}: $\approx$45\,g (typical for 18650)
    \end{itemize}

    \item \textbf{Power Distribution:}
    \begin{itemize}
        \item Buck converter regulating output to 5\,V for servos and controller
        \item Simple on/off switch for power control
        \item Note: The user must monitor battery voltage externally (no built-in protection circuit)
    \end{itemize}
\end{itemize}

%//////////////////////////////////////
%//////////////////////////////////////
%//////////////////////////////////////
%//////////////////////////////////////
%//////////////////////////////////////

\chapter{Snake Robot Software Implementation}

\section{System Architecture}
The snake robot's control software is implemented on an ESP32 microcontroller using the Arduino IDE. The system architecture comprises several integrated components:

\begin{enumerate}
    \item \textbf{Motion Control System}: Implements two primary locomotion patterns (lateral undulation and sidewinding)
    \item \textbf{Servo Motor Management}: Controls 10 servo motors in a specific layout (7 horizontal, 3 vertical)
    \item \textbf{Web-Based Interface}: Provides remote control through a WiFi access point and user-friendly HTML interface
    \item \textbf{Current Monitoring}: Measures power consumption with ACS712 current sensor
    \item \textbf{Data Logging System}: Records current measurements to the ESP32's SPIFFS filesystem
    \item \textbf{Diagnostic Tool}: Includes servo-testing.
\end{enumerate}

\section{Hardware Configuration}

\subsection{Servo Configuration}
The robot consists of 10 servo motors with a specific arrangement of horizontal and vertical actuators:

\begin{minted}[frame=single, linenos, breaklines, breakanywhere, fontsize=\footnotesize]{c++}
// Servo configuration
const int NUM_SERVOS = 10;
const int NUM_HORIZONTAL = 7;  // Number of horizontal servos
const int servoLayout[NUM_SERVOS] = {1, 0, 1, 1, 0, 1, 1, 0, 1, 1}; // 1=horizontal, 0=vertical
const int servoPins[NUM_SERVOS] = {23, 22, 2, 4, 16, 17, 5, 18, 19, 21};
\end{minted}

\subsection{Sensor Configuration}
The current sensing is implemented using an ACS712 current sensor:

\begin{minted}[frame=single, linenos, breaklines, breakanywhere]{c++}
const int analogPin = 34;
ACS712 sensor(analogPin, 3.3, 4095, 100.0); // pin, voltage, ADC max, mV/A sensitivity
\end{minted}

\section{Locomotion Control System}

\subsection{Motion Parameters}
The locomotion patterns are controlled by the following parameters:

\begin{minted}[frame=single, linenos,breaklines, breakanywhere, fontsize=\footnotesize]{c++}
// Locomotion parameters
float amplitude = 30.0;           // Degrees
float frequency = 1.0;            // Hz
float phaseOffset = 60.0;         // Degrees
float verticalAmplitude = 20.0;   // For sidewinding (degrees)
float verticalPhaseOffset = 90.0; // 90 degrees offset for sidewinding
float centerPosition = 90.0;      // Degrees
\end{minted}

\subsection{Lateral Undulation}
The lateral undulation algorithm generates a sinusoidal wave that propagates through the horizontal servos:
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

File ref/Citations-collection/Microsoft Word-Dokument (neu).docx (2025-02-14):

3D Locomotion of a Snake-like Robot Controlled by

Cyclic Inhibitory CPG Model

Zhenli Lu1,2,4 Shugen Ma1,3 Bin Li1 Yuechao Wang1

„
B. Mutual Inhibitory CPG Model

According to the mutual inhibitory theory, we adopt the

above SANs to form a CPG, as shown in Fig.3a. This mutual

inhibitory CPG is composed of ne (extensor neuron) and nf

(flexor neuron). The dynamics of the mutual inhibitory CPG

is described by the following equations:

Tn,eu˙e + ue = s0,e − ag(uf ) (3)

Tn,fu˙f + uf = s0,f − ag(ue) (4)

y{e,f} = g(u{e,f}), g(u{e,f}) = max(0, u{e,f}) (5)

c out = ye − yf (6)

where a is the weight of the mutual inhibitory connection;


s0,e and s0,f are constant, positive input, each of which is

the summation of all inputs to ne or nf by the weight of

synaptic conjunction, excepting the output of the opposite

neuron inner the CPG; ue and uf are the corresponding

membrance potentials of ne and nf ; Tn,e and Tn,f are the

corresponding time constants of ne and nf ; ye and yf are the

corresponding output of ne and nf; and c out is the output

of the CPG.

C. Cyclic Inhibitory CPG Model

According to the cyclic inhibitory theory, we adopt the

SANs mentioned in section III.A to form a CPG, as shown

in Fig.4. This cyclic inhibitory CPG is composed of ny (yaw

neuron), np (pitch neuron), and nm (modulator neuron). The

dynamics of the cyclic inhibitory CPG is described by the

following equations:

Tn,1u˙1 + u1 = s0,1 − ag(u2) (7)

Tn,2u˙2 + u2 = s0,2 − ag(u3) (8)

Tn,3u˙3 + u3 = s0,3 − ag(u1) (9)

yi = g(ui), g(ui) = max(0, ui) i = 1, 2, 3 (10)
= g(ui), g(ui) = max(0, ui) i = 1, 2, 3 (10)

y out = y1 − y3 (11)

p out = y2 − y3 (12)

where a is the weight of the cyclic inhibitory connection;

s0,1, s0,2 and s0,3 are constant, positive input, each of which is

the summation of all inputs to ny, np and nm by the weight of

synaptic conjunction, excepting the output of the neurons in

the CPG; u1, u2 and u3 are the corresponding membrance

potential of ny, np and nm; Tn,1, Tn,2 and Tn,3 are the

corresponding time constant of ny, np and nm; y1, y2 and

y3 are the corresponding output of ny, np and nm; y out and

p out are the corresponding output of the CPG to control the

yaw rotation and pitch rotation.


V. COMPUTER SIMULATION
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

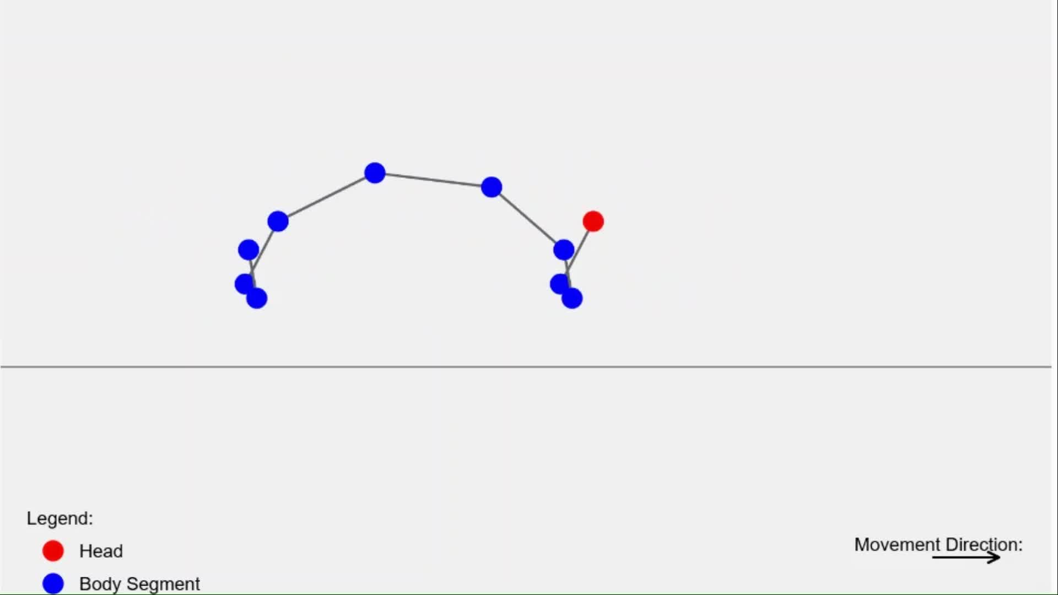
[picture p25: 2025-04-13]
docs/Latex/media/Side/ezgif-frame-6.jpg

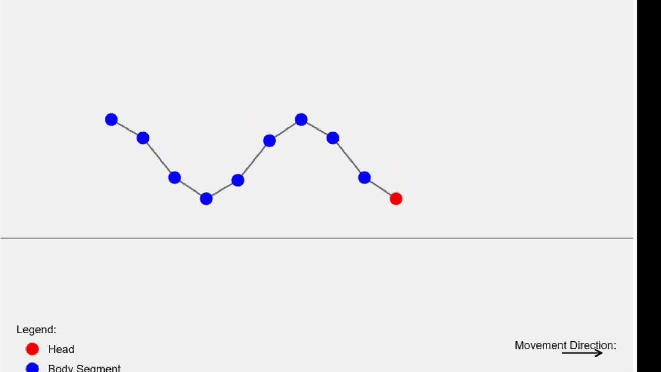
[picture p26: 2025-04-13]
docs/Latex/media/Lateral/ezgif-frame-18.jpg

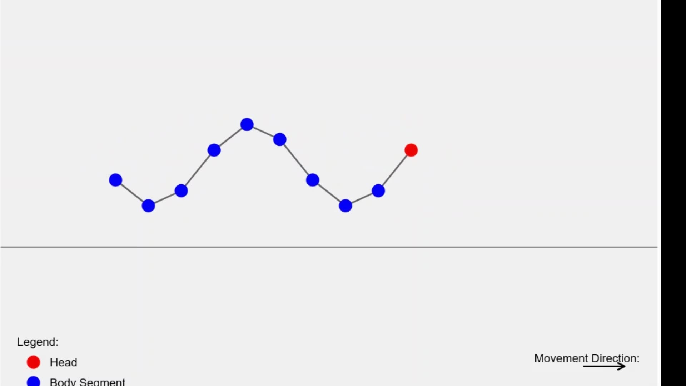
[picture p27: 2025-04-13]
docs/Latex/media/Lateral/ezgif-frame-4.jpg

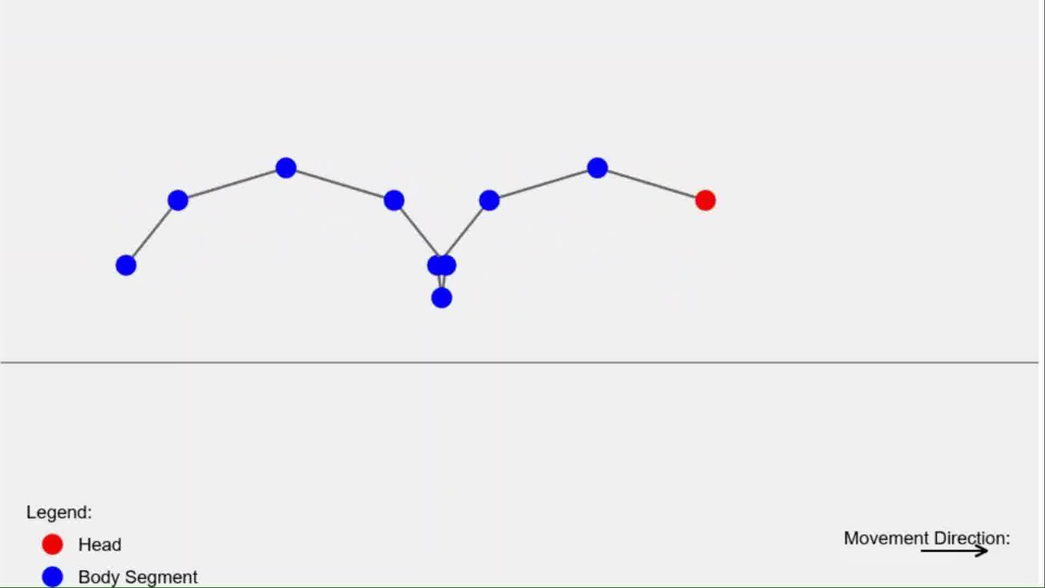
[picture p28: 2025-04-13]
docs/Latex/media/Side/ezgif-frame-14.jpg

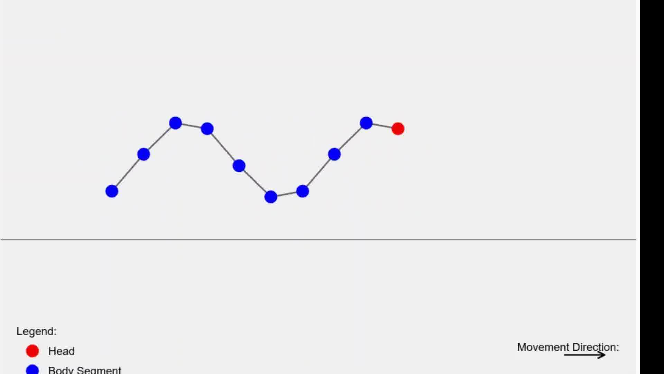
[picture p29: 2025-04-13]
docs/Latex/media/Lateral/ezgif-frame-31.jpg

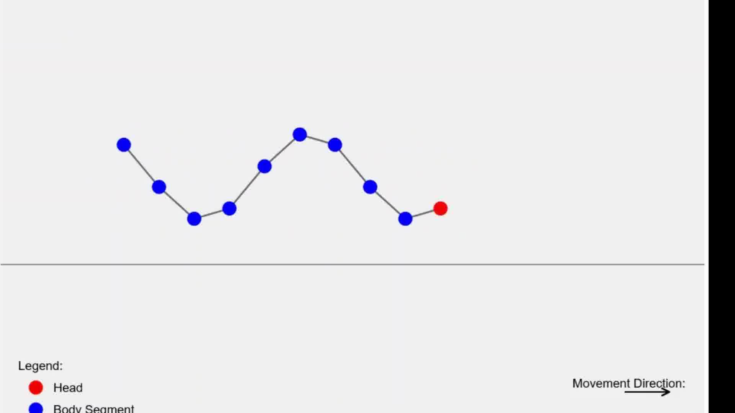
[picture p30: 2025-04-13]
docs/Latex/media/Lateral/ezgif-frame-21.jpg

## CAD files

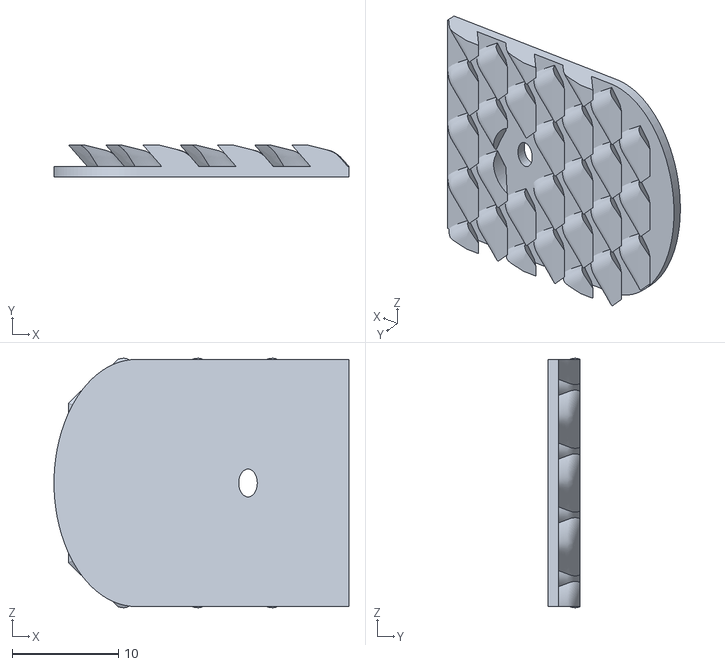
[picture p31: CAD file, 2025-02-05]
hardware/STL/V2/scales-scaled.stl
27.8 x 3.00 x 23.5

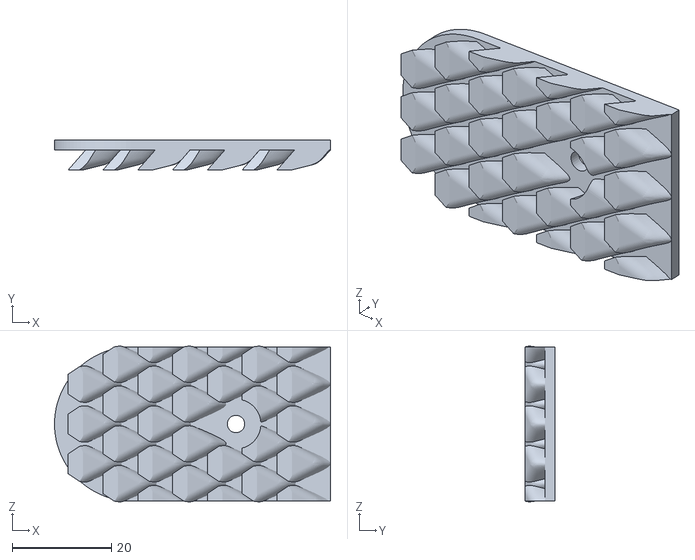
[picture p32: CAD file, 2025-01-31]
hardware/STL/V2/Passive_Scales.stl
55.5 x 6.00 x 31.3

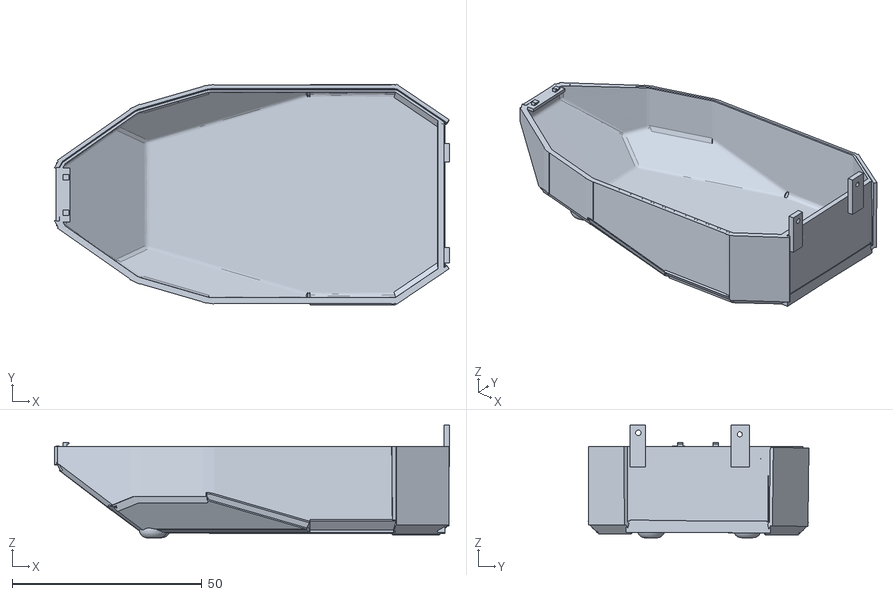
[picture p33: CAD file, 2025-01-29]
hardware/STL/V2/top-head.stl
104.0 x 58.2 x 29.7

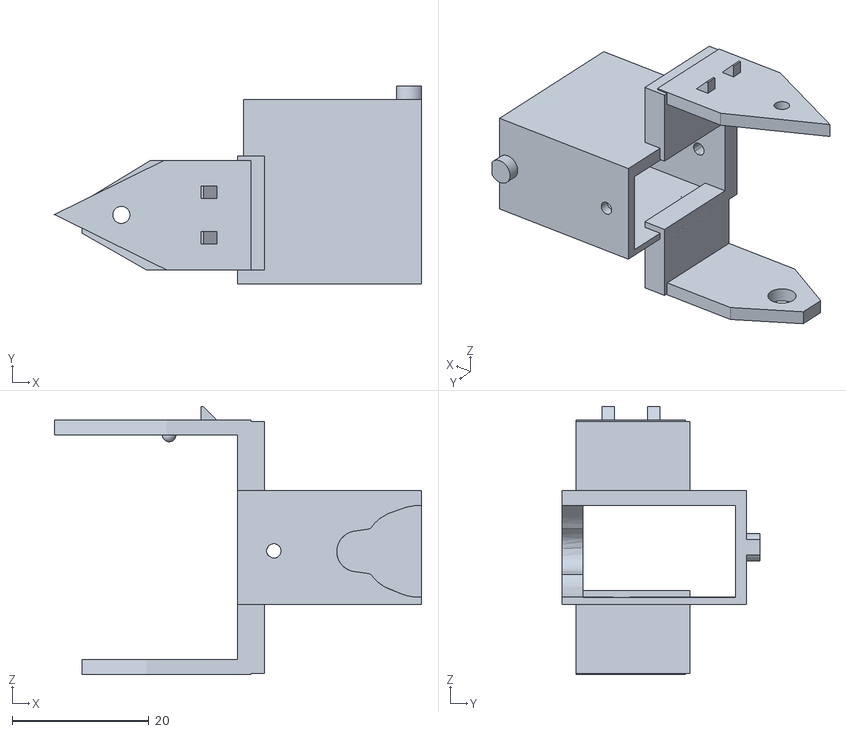
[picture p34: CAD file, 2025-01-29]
hardware/STL/V2/Vertical-holder.stl
53.8 x 29.0 x 39.3

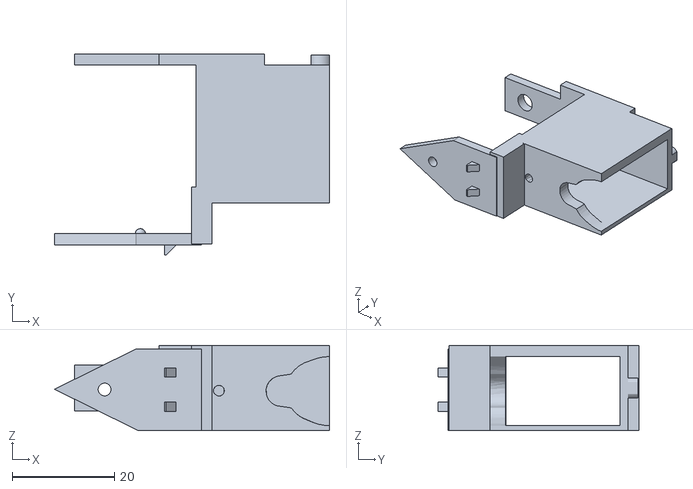
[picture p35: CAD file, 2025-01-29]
hardware/STL/V2/horizontal-holder.stl
53.8 x 39.4 x 16.7

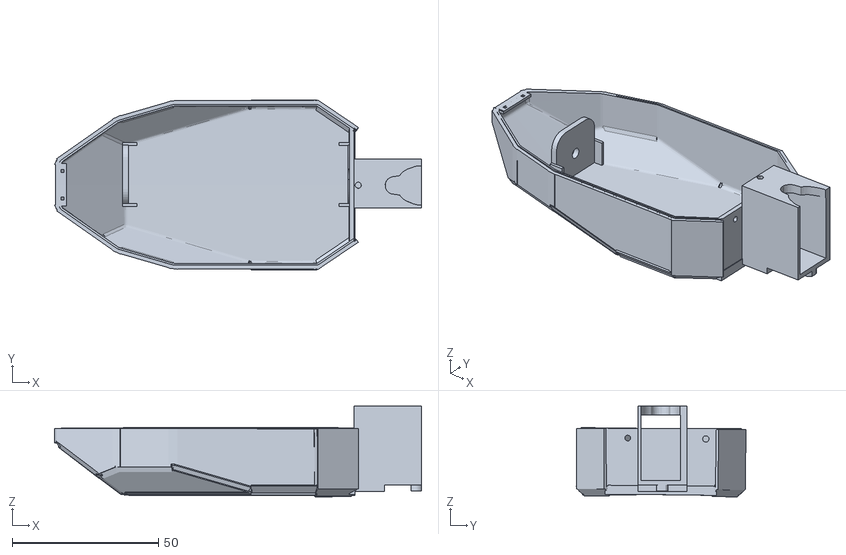
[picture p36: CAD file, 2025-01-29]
hardware/STL/V2/bottom-head.stl
125.5 x 58.2 x 31.1

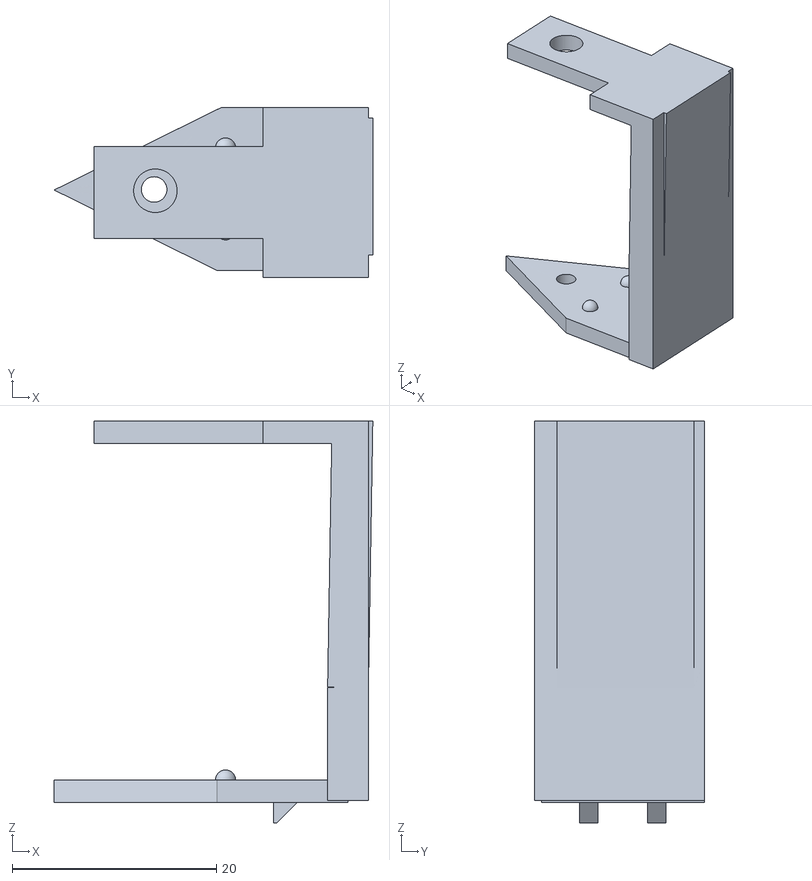
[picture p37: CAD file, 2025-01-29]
hardware/STL/V2/connector.stl
31.2 x 16.7 x 39.4

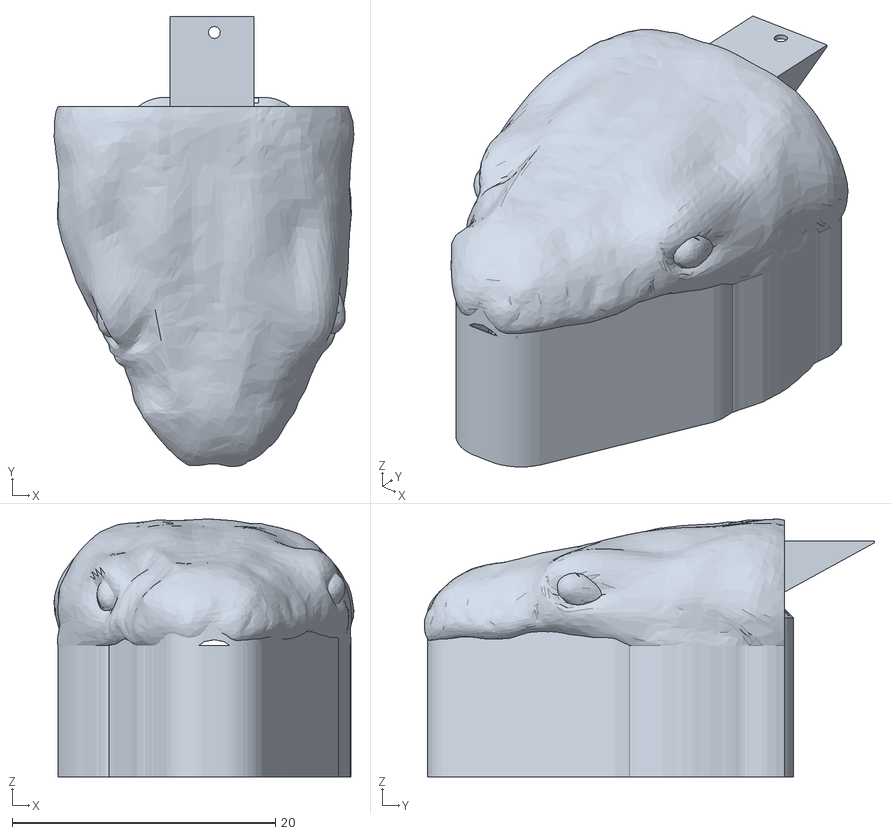
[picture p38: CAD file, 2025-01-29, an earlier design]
hardware/STL/V1/headfinal1111.stl
22.8 x 34.2 x 19.6

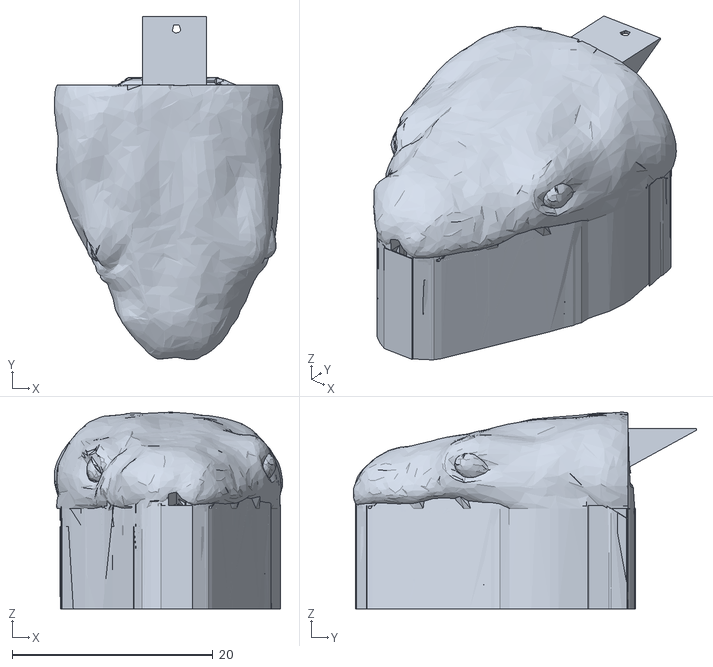
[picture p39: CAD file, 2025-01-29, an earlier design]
hardware/STL/V1/Body1.stl
22.8 x 34.2 x 19.6

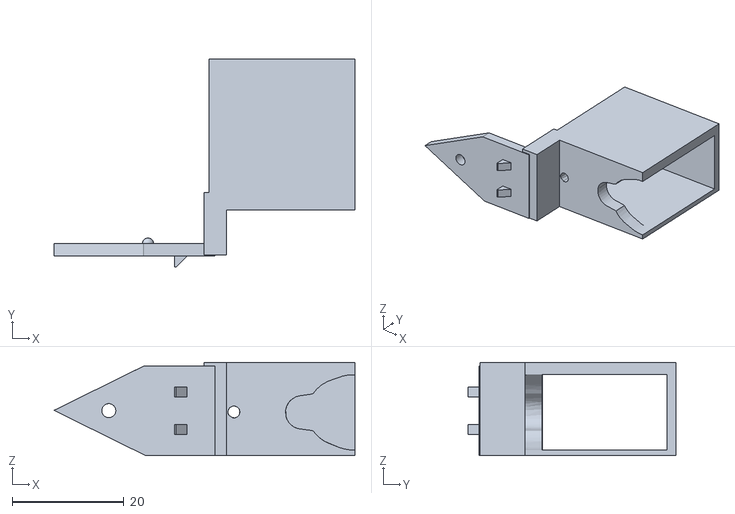
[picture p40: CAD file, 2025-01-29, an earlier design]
hardware/STL/V1/connector.stl
53.8 x 37.2 x 16.7

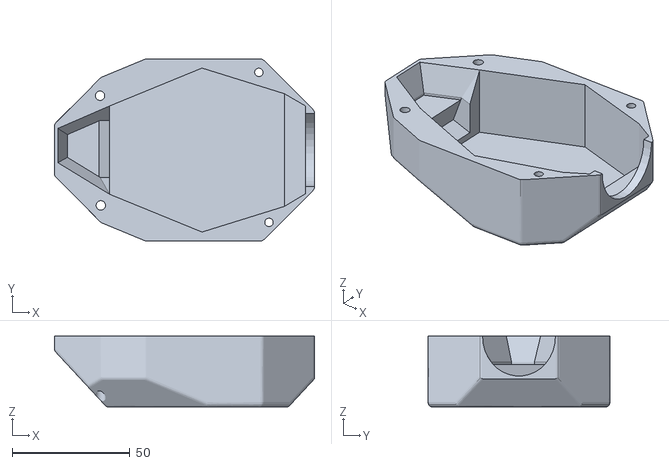
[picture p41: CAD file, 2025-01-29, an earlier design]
hardware/STL/V1/Bottom-head.stl
110.4 x 77.3 x 30.1

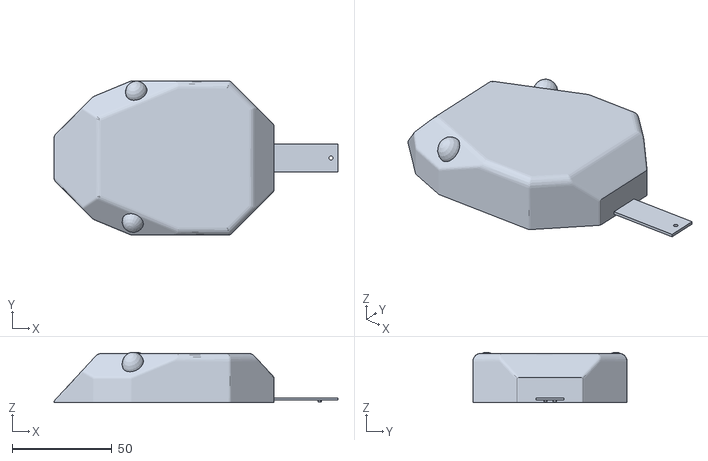
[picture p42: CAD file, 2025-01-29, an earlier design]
hardware/STL/V1/top-head.stl
142.4 x 77.3 x 25.2

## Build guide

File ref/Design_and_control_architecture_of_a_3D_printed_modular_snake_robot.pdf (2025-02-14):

# Design and Control Architecture of a 3D Printed Modular Snake Robot

Ikram Hussain Mohammed, Nicolas Gallardo, Patrick Benavidez and Mo Jamshidi Department of Electrical and Computer Engineering
The University of Texas at San Antonio
One UTSA Circle, San Antonio, TX 78249, USA Email: ikramhussainmohammed@yahoo.com, hbq744@my.utsa.edu, patrick.benavidez@utsa.edu, moj@wacong.org

Benjamin Champion
School of Engineering
Deakin University
Waurn Ponds, VIC, AUS
Email: btch@deakin.edu.au

Abstract—In this paper the design and construction of a 3D printed snake robot is presented. This snake robot has been designed to be able to complete a wide variety of tasks and motions that other snake robots are currently able to preform, such as serpentine motion, rolling and the ability to climb some objects. An approach is also investigated which allows the snake robot to be attached to the end of a serial manipulator robot to increase its available degrees of freedom. A modular design has been focused on, allowing for the fast and low cost generation and implementation of the robotic snake.
Index Terms—snake robot, modular robotics, robot, Dynamixel servos, 3D printing
I. INTRODUCTION

There are many different types of robots existing in the world today. When robots that operate on the land are considered, generally tracked or wheeled robots are used. There are many challenges that have arisen that these types of robots are unsuitable for, such as the navigation of unstable terrain such as in a collapsed building or when navigating in tight spaces like the inside of a pipe. To overcome these challenges snake robots, a many degree of freedom modular robot, have been developed. These type of robots use their many internal Degrees of Freedom (DOF) to thread through tightly pack spaces, allowing the robot to have access to locations where people or machinery cannot [1]. These robots can coordinate their internal DOF to perform a variety of movements like crawling, climbing and swimming, making it suitable for number of applications such as search and rescue in disaster site, inspection of narrow and unstructured environments like collapsed buildings and even in reconnaissance situations [2], [3]. A snake robot can also be used as end effector of a manipulator to increase the number of DOF of the robot. This paper presents a modular snake robot that combines the strengths of the current state of the art designs discussed in background section. This snake robot has been developed to achieve complicated tasks such as: climbing, smooth serpentine motion, and increase a ABB Industrial Manipulator robot’s DOF. The following paper is organized as follows: Section II presents the current research that is being conducted using snake robots. Section III details a design for a snake robot that is able to achieve the proposed tasks. Section IV presents the control architecture of the snake robot. Details on how the designed system has been tested is provided in section V. Finally, the paper is concluded and future work is presented in Section VI.

II. BACKGROUND

Before the construction of the snake robot began, research was conducted into the various different forms of snake robots that have currently been implemented refer [4]–[7]. A description of the main variants of the snake robot are as follows.
The first model of snake robot investigated was the CMU modular snake robot. This type of snake robot is able to move in a 3D manner, which allows it complete a wide variety of movements, such as climbing and linear progression, sidewinding, rolling, cornering and pipe rolling [8], where its primary form of motion is the corkscrew motion. This robot was designed with expandability in mind, as each of the segments that make up the snake robot being exactly the same, with the exception of the head and tail of the robot. Each of these unique segments contain only a single DOF, but when combined give the robot n degrees of freedom, relative to the length of the snake [8]. This snake robot was initially prototypes using a 3D printer, and is now constructed with aluminum and a rubber to provide grip and durability. This snake robot is powered and controlled via a tether [4], which makes it unable to navigate too far away from a base station. This tether could also potentially become entangled on various objects in the environment.
The next robot that was considered was the ACM-R5. This robot is the most advanced in the ACM snake robot family by Hirose and Yamada [3]. ACM-R5 is an amphibious snake robot which has ability to move both on the land and in the water. This snake robot is composed of 9 Modular Universal Units [5]. Each of these modules have two degrees of freedom with an on-board CPU and power unit. This robot has passive wheels attached which allows it to move quickly on a smooth surface. It is waterproofed using O-rings and other water proofing accessories so that it can move smoothly in the water. It can perform different motions like serpentine locomotion, concertina movement, sidewinding, S-shape and

# WAC 2016 1570259394

Authorized licensed use limited to: HTW Berlin (FH). Downloaded on February 05,2025 at 14:46:42 UTC from IEEE Xplore. Restrictions apply.

E-shape rolling, Arc-shape rolling and helical rolling but its primary motion is serpentine movement [5]. The disadvantage of this robot is it cannot climb.
Unlike the previous two snake robots considered, the next snake robot is of a different kind developed by OC robotics, the snake-arm robot [9]. This is a fixed robot, mainly being used in manufacturing applications as well as being able to be used in hazardous environments, such as a nuclear power plant. This robot has a fixed base which accommodates all the actuation and electronics required to move the robot. It is driven by a wire rope and controlled via software to get to the desired positions. It is designed with a hollow core, so cabling, hoses and other equipment can be routed though the center of arm. There are two types of snake-arm robots available for these applications, the spatial snake-arm robot and planar snake arm robot. The first robot, the spatial snake arm robot, has a total of 12 links with two DOF each. This provides a total of 24 DOF to the system. These robots are mounted on a linear axes from a fixed position, and is then deployed into the environment. This allows the robot to have sturdy base in-which to operate from, but still allows motion in a single axis in conjunction with the arm itself. This robot can also be utilized by mounting it to a mobile robot, or by attaching it to the end of a manipulator robot to increase the DOF of the robot. The second robot is planar snake robot. This robot only has the capacity to articulate itself in one plane. This robot is very compact, as it is able to save space by coiling around an actuator pack.
After analyzing the aforementioned snake robots, the strengths and weakness can be obtained. The CMU robot is very versatile as it has the ability to move with most types of snake movement, but it lacks the ability to traverse in the traditional serpentine type movement. Conversely, the ACM-R5 robot is able to use this type of movement, but is able to climb up different types of objects. The third type of robot, the snake arm robot, does not use a modular design but is able to achieve a high DOF by utilizing a series of cables attached to motors within its base. These strengths and weaknesses were considered during the design phase of the presented robot.

III. DESIGN

Each module of the 3D printed modular snake robot functions as single rotational joint with one Degree of Freedom (DOF). Every module is able to rotate 90 degrees with respect to previous module, thus enabling the generation of movement utilizing many different methods. Each module is connected to the previous module in such a way that the axis of rotation is perpendicular with respect to previous one. Having two different axis of movement in each segment pair, means that the robot is able to generate movement in all three axis given at least four segments in the chain. In other words, the modules allow for movement in both the vertical and horizontal axis, thus enabling the robot to move in a three dimensional plane. The current design consists of 16 modules including a head and tail module, which can be altered depending on the application. Having this many modules provides 16 DOF, which can be increased or decreased by simply adding or subtracting the amount of conjoined modules. Each module is 2.15 inches (5.48 cm) in diameter, and has a length of 2.95 inches (7.5 cm) in-between the joint axes.

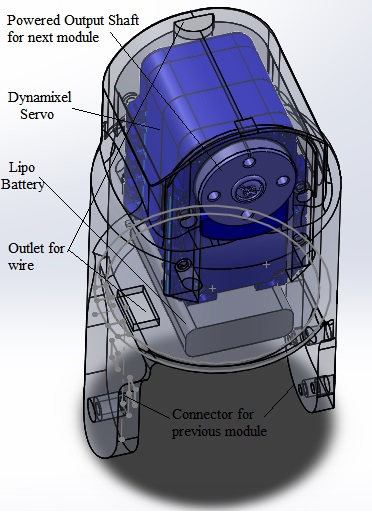
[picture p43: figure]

Fig. 1. Components of 3D Printed modular snake robot

As shown in the figure 1 the module consists of a housing, a Dynamixel servo motor, a Lithium polymer(LiPo) battery and an internal channel that allows the communication and power cables to be passed down the chain. The housing is constructed via 3D printing using PLA, a commonly used biodegradable 3D printing material, which contains all of the components within the module. The Dynamixel motor provides the torque and velocity required to provided movement to the next module. Every module has a single cell (1s) 3.7V LiPo battery inside of it, which is connected with two other modules in series to make up the 11.1 volts required to power the segments. Because of this, pairs of three modules should always be used. Each segment’s power is then connected in parallel to the rest of the snake. This will allow for any of the modules to always have enough current available to them to provide the maximum torque possible to each of the motors. It will also ensure that each segment of the snake will always be powered while the other segments of the snake are able to operate.

A. Housing
The housing consist of two parts, these being the front housing and rear housing. The front housing is the main part of the module. This contains space to house both the battery and the servo motor. To accommodate for the wires providing both communication and power to the next module, parts of the wall of the module were thinned slightly. This was done in a circular pattern around the module, as opposed to only been done in a single place, to reduce a weak-spot being made in the housing wall. The rear housing acts as a cap to cover the module. Figure 2, depicts the front and rear housing of the robot.

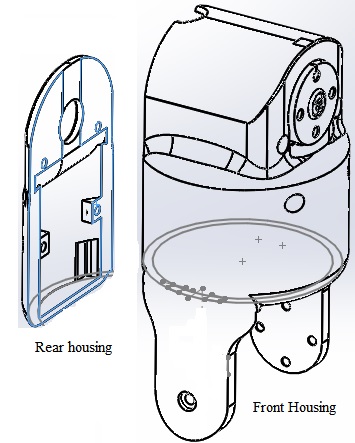
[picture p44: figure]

Fig. 2. Snake Robot Housing

To enable the many different types of movement present when snake robots are considered, a cylindrical design for the housing has been chosen. Having a cylindrical design is optimal for both rolling and climbing activities. This housing is designed in such a way that any part of the robot will not exceed 2.16 inches (5.5cm) in diameter. As the center part of the body is cylindrical, it can accommodate the structure for the passive wheel adapter, which can be attached and detached depending on the application. This passive wheel adapter will allow the robot to be able to easily preform the types of movement that a cylindrical body is not ideal for, such as the serpentine type movement.

B. Passive Wheel Adapter
As shown in figure 3, the passive wheel adapter consists of six passive wheels to be placed 60 degree apart and attached to the passive wheel support. The wheel adapter also has a small opening in the support so that it can slide over each of the modules. A screw and bolt can then be used to fasten the passive wheel support together, which enables the structure to be attached to the module. Thus with the help of this device, fast serpentine motion can be achieved whist not sacrificing the ability for the snake robot to preform the other types of motion when required.
C. Actuation
Many different types of Actuation can be used for snake robots such as pneumatic, electric motor, servos, cable ac-

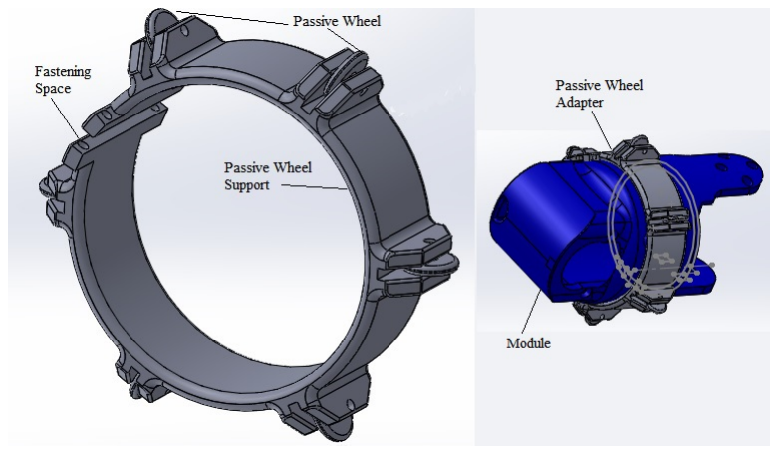
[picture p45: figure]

Fig. 3. Passive Wheel Adapter

tuation or driven wheels [9], [10]. For this robot, servo motors where considered. The Dynamixel servo motor was the chosen servo motor type, as these servo motors have an on board microprocessor to provide bus communication, positional feedback, temperature and load monitoring [11]. These motors also have adjustable torque speed and response control with Position, load, voltage, speed and temperature feedback enabling the formation of a closed loop control system with relative ease. The servos use TTL or RS-485 serial communication and allows for a daisy-chain bus connection at up to 1-3Mbps. The control algorithm used to maintain the shaft positions on the servo can be adjusted individually for each servo, allowing the user to control the speed and strength of the motor’s response. All of the sensor management and position control is handled by the servo’s built-in microcontroller. Out of the range of Dynamixel servos available, the AX-12A servo was chosen for this application [11]. This version of the servos is the most affordable servo with built in microcontroller. It operates at 12V 900mA, weighs 55g and provides a stall torque of 15.3 kg.cm. These servos use TTL half-duplex asynchronous serial communication as well as including all of the features mentioned above. Thus due to these advantages and the affordable cost of the servo, this servo motor was chosen and implemented in this application.

D. 3-D Printing
The technique of 3D printing is used to prototype the casing of this robot. 3D printing, or additive manufacturing, is a process of creating three dimensional solid objects from a digital file [12]. The creation of a 3D printed object is achieved using the additive processes, as opposed to the subtractive process used by most other techniques, such as by a CNC machine. The process utilized by this additive manufacturing machine involves an object being created by laying down successive layers of material on top of each other until the whole object is created, refereed to as the Fused Deposit Modeling method. Each of these layers can be seen as a thinly sliced horizontal cross-section of the eventual object [13]. The digital file of the object to be printed is made using a 3D scanner, to copy an existing object, or in a Computer Aided Design (CAD) program for the creation of a totally new object. After the model has been completed, the file can then be saved in a general file type, such as the STL format, which is processed by software knows as a slicer. This software converts the model into a series of thin layers and produces a G-code file containing instructions tailored to a specific type of 3D printer which enables the printer to create the model. 3D printing helps in the fast prototyping process which saves time and money. This is a big advantage as if the same parts were to be manufactured by hand it would take a significant amount of time to complete, as well as being very expensive due to the labor and machine costs involved. While 3D printing the first module, it was easy to find problems in the design, rectify it and then print the design again. Because of this, the design of the module was able to be easily changed to accommodate for new communication and power lines. Each module of the snake robot was printed on the Lulzbot Taz 4 which is an open source 3D printer. It supports material such as PLA, ABS, HIPS, Ninja Flex etc. Among these materials, PLA (Poly-lactic Acid) was selected as it demonstrates significantly less part warping, higher maximum printing speeds, lower layer heights, sharper printed corners and affordable pricing compared to some of the other options. The virtual design for printing the module is designed in CAD software, in this case using SolidWorks, and saved in the STL format. This file is then opened in Cura LulzBot, which acts as the slicer and therefore converts the model into GCODE as well as allowing the user to control the operation of the 3D printer.
Unfortunately there are some disadvantages when using 3D printed parts of this nature, as they are generally not as strong, or as durable, as parts that might be constructed using other methods. Because of this, 3D printing is used for the prototyping stage of this robot. If this robot was to be taken to a potentially hazards environment, such as a collapsed building or a site where there might potentially be corrosive material, the casing for the modules would need to be produced using either more traditional methods with stronger metal materials, or be constructed using an industrial grade 3D printer.
E. Implementation
The implementation is done both in software and hardware. Figure 4 shows the assembly of the module in the CAD software depicting all of the modules connected together to form the robot. This simulation helps to find the problems associated with the design and to study the movements of the robot before the physical models are produced. Figure 5 illustrates the model of the snake robot after the 3D printing process. As can be seen, all of the modules have been assembled to each other and wired showing the completion of the robotic snake.
F. Cost
A breakdown of the components and their cost are provided in Table I. The most expensive components of the robot are the Dynamixel servos. The features the servos provide are deemed worthy of the cost. Each servo has an on-board microprocessor

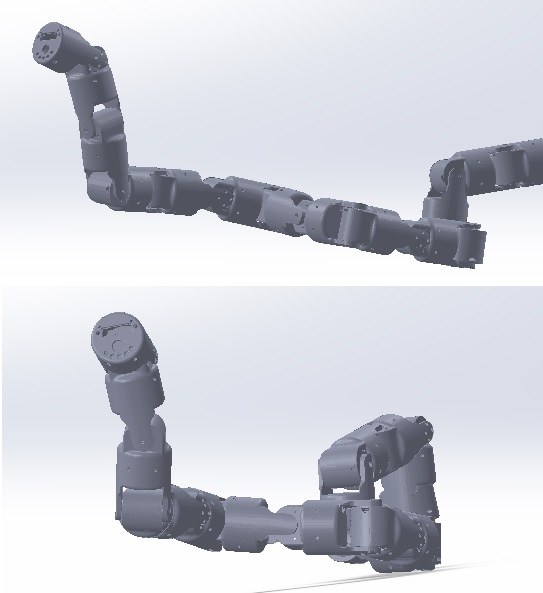
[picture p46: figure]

Fig. 4. CAD Model

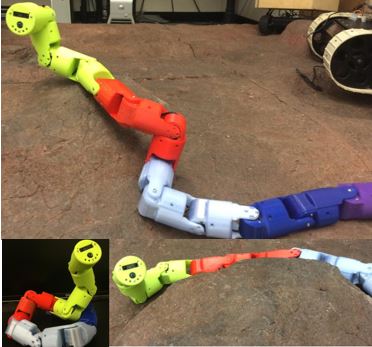
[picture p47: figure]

Fig. 5. 3D Printed Robotic Snake

that provides bus communication, motor state feedback such as positional, load, voltage, speed and temperature feedback [11]. Other relevant features enable the formation of a closed loop control system with relative ease as discussed under actuation section.

No | ITEMS | QTY | Unit($) | Total Cost($)
1 | AX-12 Dynamixel Servo | 16 | $37.50 | $600.00
2 | USB2Dynamixel | 1 | $49.90 | $49.90
3 | Lipo Battery (3.7V 750mAh) | 15 | $3.50 | $52.50
4 | 3D printing filament | 1 | $24.95 | $24.95
5 | Raspberry Pi Zero | 1 | $5.00 | $5.00
6 | USB Hub | 1 | $10.99 | $10.99
7 | Camera | 1 | $33.90 | $33.90
8 | IMU | 1 | $29.95 | $29.95
9 | IR Sensor | 1 | $13.95 | $13.95
10 | Wifi Module | 1 | $8.99 | $8.99
11 | Miscellaneous | | | $65.00
| | | Total | $895.13

TABLE I
MEASUREMENT RESULT OF EXP.1

IV. CONTROL ARCHITECTURE
Different approaches have been considered to control the presented robotic snake. The first approach that was considered is embedding a microcomputer directly into the head unit of the snake, such as an ODROID, Raspberry Pi or Raspberry Pi zero. This will allow for the local control of the robot, as Robotic Operating System (ROS) is able to run on-board. The next feasible approach that has been considered is to utilize a simple micro controller, such as the Arduino Nano or Arduino Mega 2560, equipped with a Wi-Fi module to enable communication back and fourth from a processing unit, such as a laptop. This will enable the use of ROS to control the robot for actuation, will also enable future applications. A description of the proposed setup is depicted in figure 6. The Raspberry Pi zero was chosen as the control unit for the system. The main reasoning behind this is that it is a very small and inexpensive microcomputer. It also has the advantage of having a form factor similar to that of a microcontroller, thus allowing the modular system to stay relatively small.

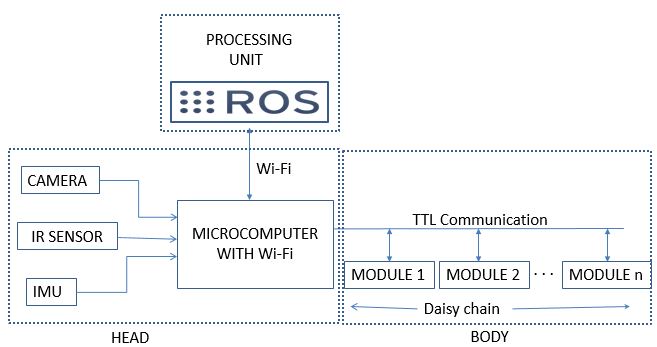
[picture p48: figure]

Fig. 6. Block Diagram

A. Processing Unit
They are many options for the processing unit that can be used, such as an ODROID, Raspberry Pi or Raspberry Pi Zero. Currently Robot Operating System (ROS) is installed onto a Raspberry Pi Zero which is able to control the angle of each of the connected servos, as well as interpret feedback from the servos such as position and temperature of each of each servos.

ROS is an open source meta-operating system that provides a message passing interface between processes across a network of installed nodes [14]. These nodes do not have to be located on the robot, which makes it ideal for a mobile robot as processing can be moved to another unit, assuming it is on the same network. Utilizing a common messaging systems such as ROS also allows the system to be easily integrated into a much larger system that is also utilizing this messaging system. This principle is being used at the moment as a Laptop is able to use the ROS environment to access and transmit information to and from the Raspberry Pi Zero.

B. Head

The head consists of a camera, an IR sensor, an IMU and the Raspberry Pi zero. The head is also equipped with an LED for illumination during pipeline inspection, at night and in a dark environment. The IR sensor is used to find the distance of an obstacle or an object in front the robot. This is helpful as it allows the robot to pick an object when the an end effector is attached to the head of the snake. An Internal Measurement Unit (IMU) with 10DOF is used, which gives 11 axes of data: 3 axes of accelerometer data, 3 axes gyroscopic, 3 axes magnetic (compass) and temperature which makes it possible for many different applications [15]. The microcomputer used is raspberry pi zero, which acts as a data exchange hub. All of the different sensors, as well as the servo motors, are attached to the Raspberry Pi Zero via a USB hub. Using a standard connection such as a USB, also enables for the rapid expandability of the system as many different sensors have this interface available. The Raspberry Pi zero collects all of the available data from the robot such as the camera, IR, IMU, Position, load, voltage, speed and temperature data and sends it to the processing unit via a Wi-Fi connection. The processing unit calculates the required positions that the servo needs to be in. This information is then transmitted to the microcomputer, which is able to move the attached servos to the desired positions.

C. Body

The body consist of a chain of modules connected together in series. The servos inside the module uses TTL serial communication to receive commands and send back sensor data to the microcontroller. A daisy-chain wiring scheme is applied to this system, in which multiple servo are connected together in a series sequence, thus reducing the number of wires required in the robot. This daisy-chain approach also allows for the system to be quickly scaled up or down as needed.

V. TESTING AND APPLICATIONS

The system has been tested to generate different types of 3D patterns by connecting the system directly to computer via a TTL to USB converter. A Dynamixel servo library generated for ROS was used, with the help of a python script to implement square wave motion as shown in Figure 7.

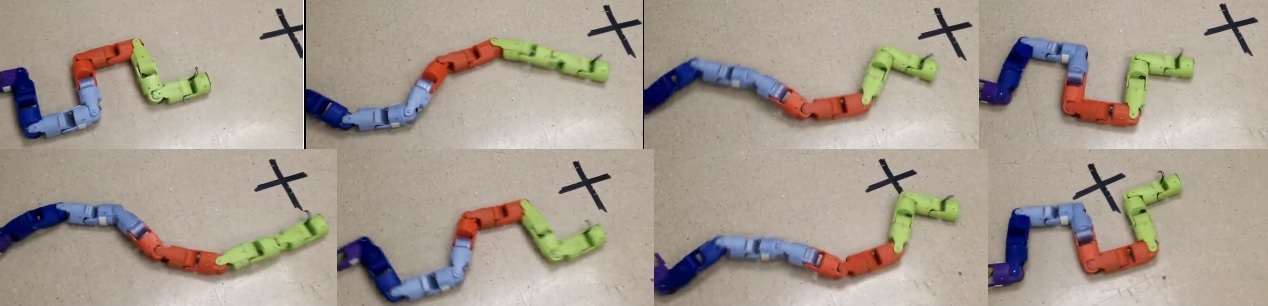
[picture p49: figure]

Fig. 7. Snake robot performing square wave motion

Implementation of other types of movement are still under development.
Another application that this system can be applied to is to be used as an end effector for a ABB robot as depicted in figure 8. If the robot that the snake is attached to also functions via the ROS system, the two system can be easily integrated into one another.

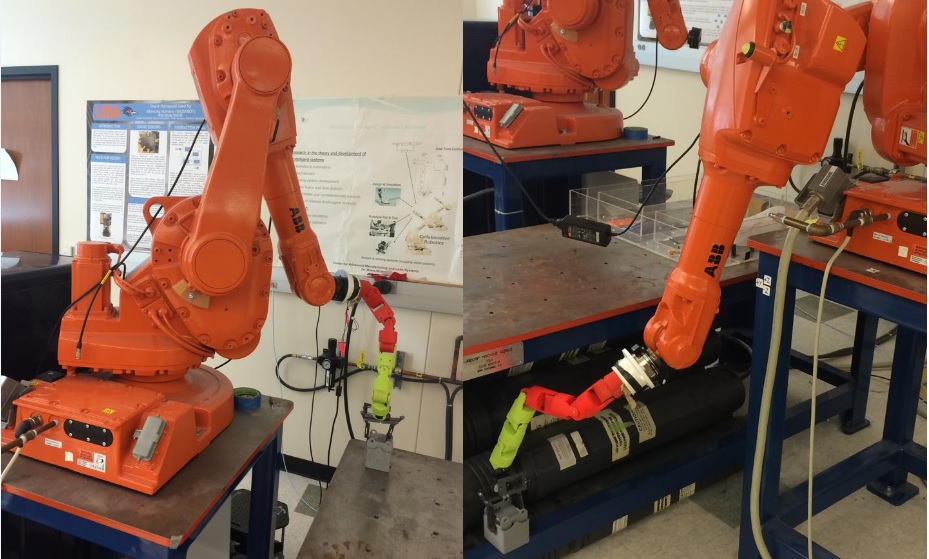
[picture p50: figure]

Fig. 8. Snake robot used as End effector for an Industrial Robot

VI. CONCLUSIONS AND FUTURE WORKS
In this paper a design for a 3D printed modular snake robot was presented which is low cost and was able to be constructed in a relatively short period of time. A control architecture for the snake robot has also been presented focusing on using a microcomputer to control the snake, with complex processing being undertaken outside the unit.
The implementation of all of the presented motions will be undertaken in the future, with the complete integration of the snake robot into a serial manipulator robot, as well as the robot to be integrated into a system of other robots to be investigated.

REFERENCES

[1] C. Wright, A. Johnson, A. Peck, Z. McCord, A. Naaktgeboren, P. Gianfortoni, M. Gonzalez-Rivero, R. Hatton, and H. Choset, “Design of a modular snake robot,” in Intelligent Robots and Systems, 2007. IROS 2007. IEEE/RSJ International Conference on. IEEE, 2007, pp. 2609– 2614.
[2] A. Johnson, C. Wright, M. Tesch, K. Lipkin, and H. Choset, “A novel architecture for modular snake robots,” Citeseer, Tech. Rep., 2011.
[3] S. Hirose and H. Yamada, “Snake-like robots [tutorial],” Robotics & Automation Magazine, IEEE, vol. 16, no. 1, pp. 88–98, 2009.
[4] C. Wright, A. Buchan, B. Brown, J. Geist, M. Schwerin, D. Rollinson,
M. Tesch, and H. Choset, “Design and architecture of the unified modular snake robot,” in Robotics and Automation (ICRA), 2012 IEEE International Conference on. IEEE, 2012, pp. 4347–4354.
[5] S. Yu, S. Ma, B. Li, and Y. Wang, “An amphibious snake-like robot: Design and motion experiments on ground and in water,” in Information and Automation, 2009. ICIA’09. International Conference on. IEEE, 2009, pp. 500–505.
[6] A. Crespi and A. J. Ijspeert, “Amphibot ii: An amphibious snake robot that crawls and swims using a central pattern generator,” in Proceedings of the 9th international conference on climbing and walking robots (CLAWAR 2006), no. BIOROB-CONF-2006-001, 2006, pp. 19–27.
[7] T. Aoki, H. Ohno, and S. Hirose, “Design of slim slime robot ii (ssr-ii) with bridle bellows,” in Intelligent Robots and Systems, 2002. IEEE/RSJ International Conference on, vol. 1. IEEE, 2002, pp. 835–840.
[8] Modular | snake | robots:gaits. | [Online]. | Available:
http://biorobotics.ri.cmu.edu/projects/modsnake/newwebsite/gaits/
[9] Snake-arm | robots. | [Online]. | Available:
http://www.ocrobotics.com/technology-/snakearm-robots/
[10] K. J. Dowling, “Limbless locomotion: learning to crawl with a snake robot,” Ph.D. dissertation, NASA, 1996.
[11] Dynamixel-ax-12a-servo. | [Online]. | Available:
http://www.generationrobots.com/media/Dynamixel-AX-12-usermanual.lpdf
[12] 3d printing - wikipedia, the free encyclopedia. [Online]. Available: https://en.wikipedia.org/wiki/3D-printing
[13] What is 3d printing? how does 3d printing work? [Online]. Available: http://3dprinting.com/what-is-3d-printing/
[14] Robotic | operating | system. | [Online]. | Available:
https://en.wikipedia.org/wiki/Robot Operating System
[15] Imu. [Online]. Available: https://www.adafruit.com/product/1604

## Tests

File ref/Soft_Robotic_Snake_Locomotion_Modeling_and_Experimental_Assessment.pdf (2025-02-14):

## Soft Robotic Snake Locomotion: Modeling and Experimental Assessment

Dimuthu D. K. Arachchige¹

, Yue Chen²

, and Isuru S. Godage¹

Abstract— Snakes are a remarkable evolutionary success story. Numerous snake-inspired robots have been proposed over the years. Soft robotic snakes (SRS), with their continuous and smooth bending capability, can better mimic their biological counterparts’ unique characteristics. Prior SRSs are limited to planar operation with a limited number of planar gaits. We propose a novel SRS with spatial bending ability and investigate snake locomotion gaits beyond the planar gaits of the state-of-the-art systems. We derive a complete floating-base kinematic model of the SRS and use the model to derive joint-space trajectories for serpentine and inward/outward rolling locomotion gaits. These gaits are experimentally validated under varying frequency and amplitude of gait cycles. The results qualitatively and quantitatively validate the proposed SRSs’ ability to leverage spatial bending to achieve locomotion gaits not possible with current SRS designs.

I. INTRODUCTION
Snakes are highly capable animals with a wide range of habitats, including hostile deserts, dense tropical forests, and uninhabitable marshes. One key feature that makes snakes unique in their ability to navigate in different terrains using various locomotion gaits is supported by their long, high degrees of freedom (DoF) slender bodies. The body’s continuous and smooth bending structure enables snakes to overcome numerous environmental challenges such as climbing, swimming despite having no sophisticated appendages such as limbs. Their high DoF body can generate a range of locomotion gaits such as lateral undulation, rectilinear movement, sidewinding, concertina m7ovement. Snake-like robots can harness this traversability in different and challenging terrains in applications such as inspection tasks, reconnaissance, search, and rescue operations. Their small cross-section to length ratio allows them to gain access through tight spaces, little narrow openings (i.e., sewage lines), and perform assigned operations. Robotics have developed various snake robot prototypes [1]–[9] to meet the aforementioned application challenges.
A. Prior Work
Prior work on snake robots mainly evolved with modular rigid robots [1], [4]–[6]. Rigid robotic snakes (RRS) use jointed rigid links to achieve bending motion and generate

1Dimuthu D. K. Arachchige and Isuru S. Godage are with the Robotics and Medical Engineering Laboratory, School of Computing, DePaul University, Chicago, IL, 60604. darachch@depaul.edu. 2Yue Chen is with the Department of Mechanical Engineering, University of Arkansas Fayetteville, AR, 72701.

This work supported in part by the National Science Foundation grants IIS-1718755, IIS-2008797, IIS-2048142, UARK Chancellor’s Fund for Innovation and Collaboration, and DePaul University Academic Initiative Grant 602034.

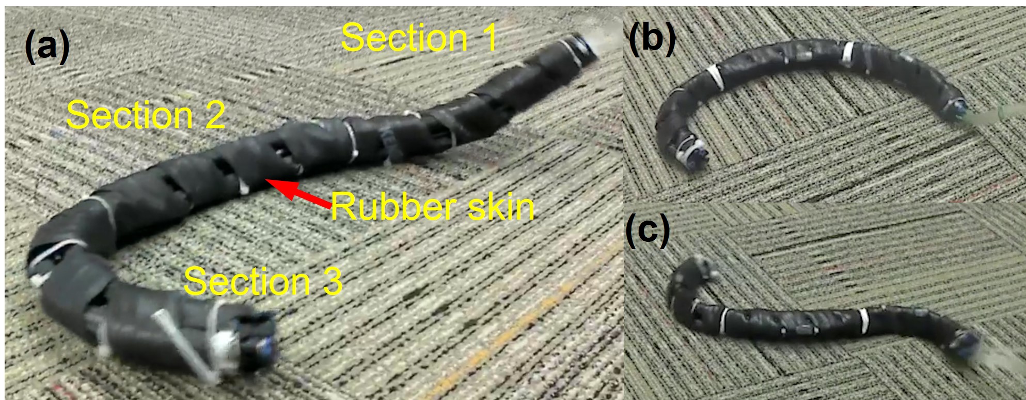
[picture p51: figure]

Fig. 1: The proposed (a) Soft robotic snake (SRS) prototype replicating (b) rolling locomotion, and (c) serpentine locomotion.

locomotion. RRS, with few rigid links, limits the robot from achieving the smooth bending observed in snakes and, therefore, can affect locomotion. On the other hand, soft robotic snakes (SRS), constructed mainly from fluidic muscle actuator-powered bodies, can better leverage smooth bending to imitate snake body movements. However, the latest SRS prototypes are limited to planar bending deformation, limiting the number of gaits they can demonstrate [10]. In addition, snakes use differential friction property of their skin to generate locomotion in planar gaits such as serpentine gait [11]. Without such friction profiles in SRS, it is challenging to propel robots solely via planar locomotion gaits. Thus, current SRS rely on wheels to circumvent uniform friction and generate locomotion [9], [10]. Similarly, the SRS reported in [8], [12], [13] use wheels to generate serpentine locomotion. The SRS presented in [14] and [15] is self-contained with integrated sensing and feedback control. It improves the accuracy of dynamic undulatory locomotion. Branyan et al. in [16] have focused on snakeskin properties to improve locomotion. We posit that it is essential to exploit the out-ofplane deformation (spatial bending) to replicate locomotion gaits such as rolling and sidewinding that rely less on anisotropic friction. We propose a novel SRS with spatial bending capabilities to address some of these limitations in state-of-the-art designs.

B. Contribution
The main contributions of this work are (a) propose a novel SRS with spatial bending capability, (b) derive complete floating base kinematic model, (c) derive joint-space trajectories of serpentine, inward rolling, and outward rolling snake locomotion gaits, (d) experimentally validate the said locomotion gaits for a range of pressure-frequency combinations on the propose SRS, (e) demonstrate the need for spatial bending to overcome the limitations of friction anisotropy present in practical SRS. The experimental results show that SRS can successfully track the spatial shape trajectories for

2021 IEEE 17th International Conference on Automation Science and Engineering (CASE) August 23-27, 2021. Lyon, France

978-0-7381-2503-9/21/$31.00 ©2021 IEEE | 805
2021 IEEE 17th International Conference on Automation Science and Engineering (CASE) | 978-1-6654-1873-7/21/$31.00 ©2021 IEEE | DOI: 10.1109/CASE49439.2021.9551398

Authorized licensed use limited to: HTW Berlin (FH). Downloaded on February 05,2025 at 14:47:16 UTC from IEEE Xplore. Restrictions apply.

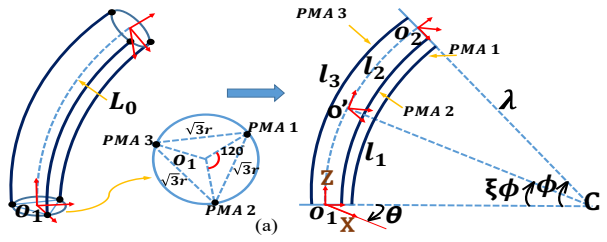
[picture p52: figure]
PMA 1; PMA 3; PMA 2

(b)

Fig. 2: A schematic of a single section and a schematic of the SRS.

the rolling gaits very well. This SRS utilizes spatial bending capability and demonstrates meaningful locomotion (using inward/outward rolling gait) without wheels. The locomotion is supported by the friction forces generated solely through snake skin-ground interactions.

II. SYSTEM MODEL

A. Prototype Description

Fig. 1 shows the prototype of the proposed SRS. It is made of three serially attached soft bending modules (or sections). They are powered by McKibben type extending mode pneumatic muscle actuators (PMA) [17]. These actuators proportionally extend the body to supplied pneumatic pressure up to 4 bars. In a single soft module, 3 PMAs are assembled at π
3

separation from each other to ensure symmetric spatial bending and facilitate room to route pneumatic supply lines within the module for a streamlined physical profile required for a slender snake-like body. Each PMA has an unactuated length, Li0=0.15 m, and can extend by 0.065 m at 4 bar pressure. Rigid 3D printed mounting frames (made of ABS thermoplastic) are used to mount PMAs at ri=0.0125 m from the centerline of soft modules (Fig. 1). Similarly, laser-cut plastic constrainer plates of ri and 0.0025 m thickness are used along the soft modules’ length to maintain PMAs parallel to soft modules’ central axis with a ri clearance from the central axis. The constrainer plates also provide structural strength for this long and slender SRS to maintain its structural integrity during locomotion and generate reaction forces required for locomotion. All actuators are bundled within the soft module as a single unit, similar to the continuum sections reported in [18]. The pressure differential among PMAs of a soft module causes the module to bend in any direction or extend axially. Thus we can control the bends synchronously in order to generate various types of robot locomotion gaits. Soft modules are then connected via the mounting frames at a π
3

offset to each
other to create the SRS (Fig. 1). Finally, the SRS is wrapped with rubber skin, and without the pneumatic supply lines, it weighs close to 0.3 kg.

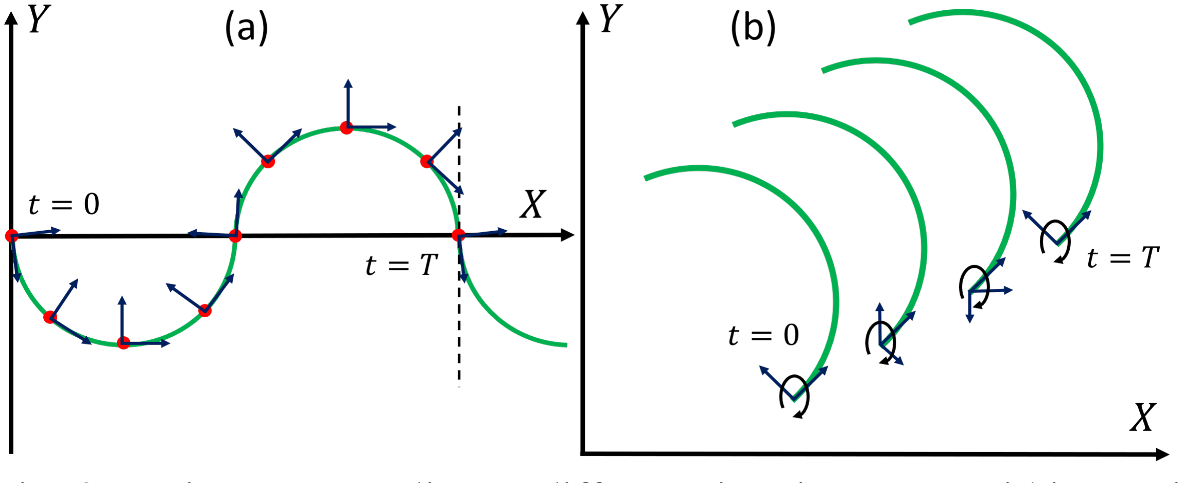
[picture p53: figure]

Fig. 3: Trajectory sampling at different time instances within a gait cycle for (a) serpentine gait and (b) outward rolling gait.

B. Kinematic Model
Consider the schematic of any i

th module (i ∈ {1,2,3}) of the SRS, as shown in Fig. 2-a. It depicts three mechanically identical variable length actuators (i.e., PMAs) with an unactuated length Li0 ∈ R and length change li j(t) ∈ R, where j ∈ {1,2,3} is the actuator index, and t is the time. Hence, the length of an actuator at any time is Li j = Li0 +li j(t). The kinematic model of the proposed SRS can be formulated by extending the modal kinematics proposed by Godage et al. in [19]. Let the joint-space vector of any i

th soft robot
module be qi = [li1 (t), li2 (t), li3 (t)]T
. Utilizing the results
from [19], we can derive the homogeneous transformation matrix (HTM) at any point along the neutral axis of the i

th
soft module, Ti ∈ SE3
, as

Ti(qi

,ξi) =
Ri(qi

,ξi) pi
(qi

,ξi)

0 | 1 | Rz (σi) px
(δi)
0 | 1
(1)

where Ri ∈ SO3
is the rotational matrix, pi ∈ R
| 3 is the
position vector ξi ∈ [0,1] is a scalar to define points along the soft module with 0, and 1 denotes the base and the tip, and I3 is the rank 3 identity matrix. In addition to the previous results in [19], note that we introduce two HTMs with Rz ∈ SO3
is the rotation matrix about the +Z axis, and px ∈ R

3
is the position offset along the +Z of O
| 0 i where
σi ∈ [0,2π].
Utilizing (1) with a floating-base coordinate system, Tb ∈
SE3
, the complete kinematic model along the body of the snake robot (Fig. 2-b) is given by

T(qb

,q,ξ ) = Tb (qb
)

3
∏

i=1

Ti(qi

,ξi)

=

R(qb

,q,ξ ) p(qb

,q,ξ )

0 | 1 |
(2)

where qb = [xb, yb,zb,α,β, γ] are the parameters of the floating coordinate system with [xb, yb,zb] denote the translation and [α,β, γ] denote the XYZ Euler angle offset of the base of module 1, i.e., the origin of the robot coordinate frame, with respect to {O}. The composite vector q = [q1
| | ,q2, ,q3

] ∈ R

9
and ξ = [0,3] ∈ R.

III. TRAJECTORY GENERATION
In this work, we consider serpentine, inward rolling, and outward rolling locomotion gaits, which are cyclic in nature. We can mathematically model these gaits associated with different locomotion gaits to generate the taskspace

806

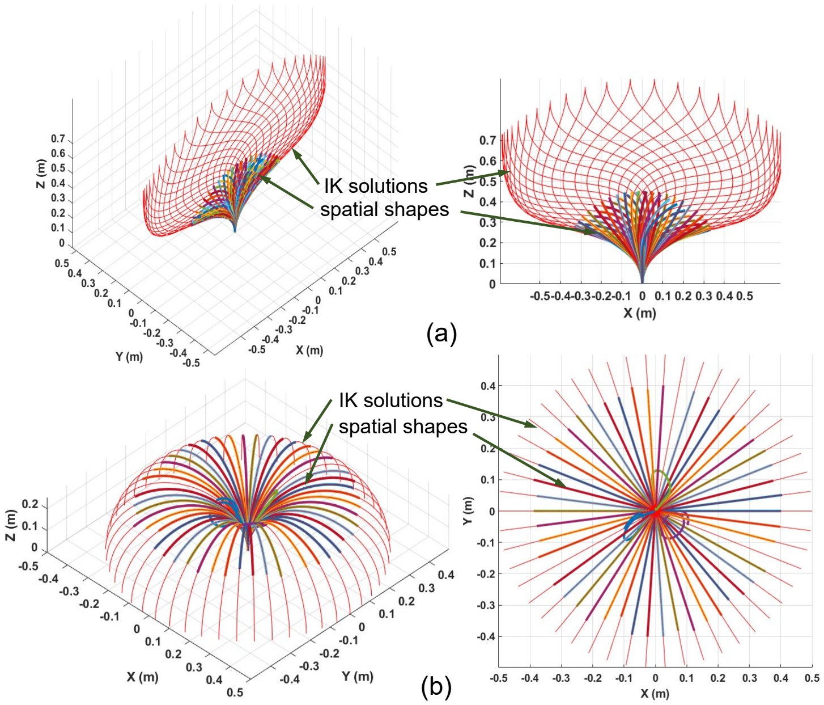
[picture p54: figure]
spatial shapes; IK solutions

Fig. 4: Trajectory curves in the robot coordinate frame: (a) Serpentine locomotion, (b) Rolling locomotion.

trajectories thereof. Fig. 3 shows the taskspace trajectories of serpentine and outward rolling locomotion. The serpentine curve is given by

x (s) = Z s

0

cos(acos(bσ) +cσ)dσ

y (s) = Z s

0

sin(acos(bσ) +cσ)dσ | (3)

where a = −

pi
4

, b =

pi
4

, c = 0, and z(s) = 0.
The rolling gait can be modeled as a mathematical curve – in this case, the displacement of a circular arc with radius rR, in the rolling gait. One cycle of the rolling gait is defined as the rotation of the curve about its longitudinal axis (Z-axis in the robot coordinate frame), and the robot displacement on the X-Y plane is due to the thickness of the robot that can be derived as 2πri

, where ri

is the radii of soft modules. From one period of a gait, we derive spatial shapes from the curve at different time intervals within one locomotion cycle to obtain different spatial shapes resembling the snake shape at each of those instances. Similarly, Fig. 3 shows the progression of the serpentine gait and inward rolling gait in one cycle. The dots along the serpentine curve, shown in Fig. 3-a denote the robot origin of the robot coordinate frame at the sampling time instances. Similarly, Fig. 3-b shows the rolling locomotion progression at different time instances. Next, we map these spatial shape trajectories to the joint-space trajectories of the SRS. The kinematic model we derived in Sec. II-B, given by (2) has a floating base coordinate that denotes the origin of the SRS with respect to the inertial frame. However, the floating DoFs are redundant for generating the bending shape of the robot. We follow the steps outlined below to identify the shapes and project those shapes to the SRS’s coordinate system.
From the progression of the locomotion gait at different times within a period, we define the curves’ origin at those points (Fig. 3). Without losing generality, consider any n
| th

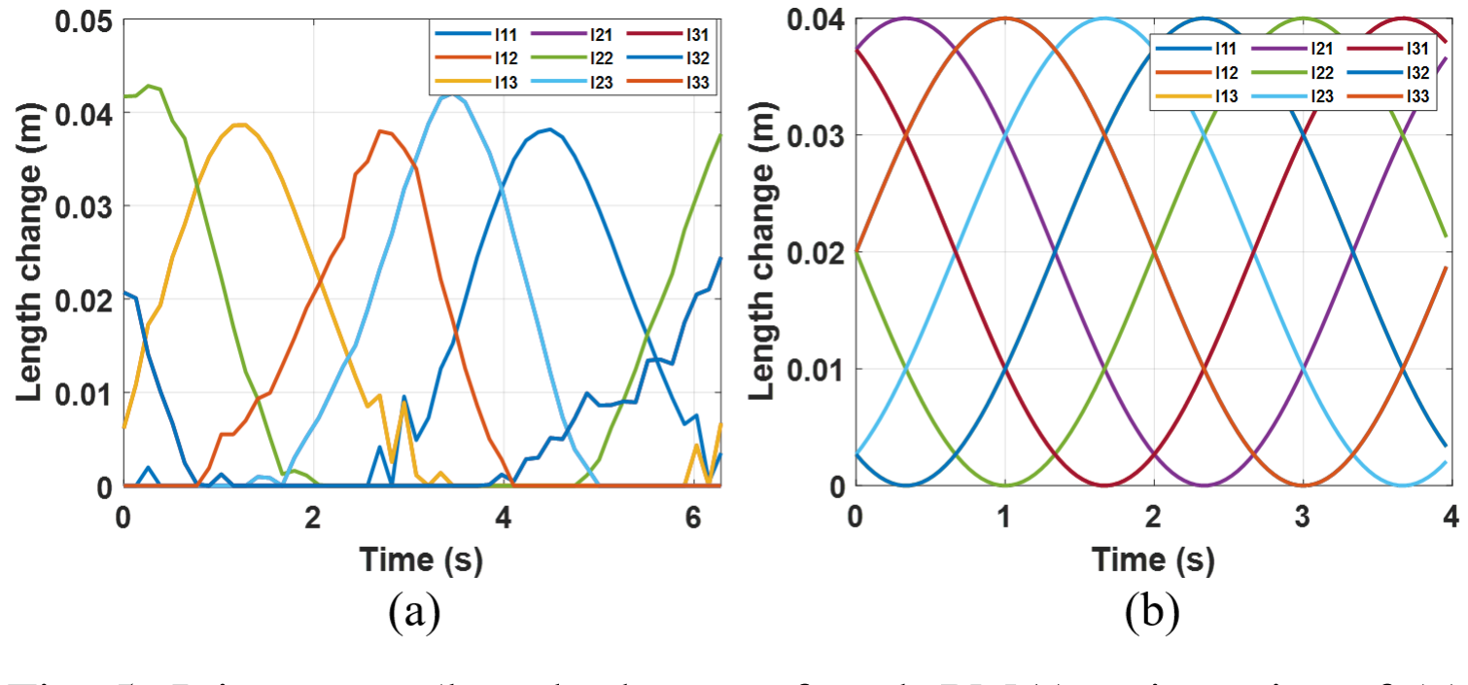
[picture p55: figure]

Fig. 5: Joint-space (length change of each PMA) trajectories of (a) serpentine gait, (b) rolling gait for a single cycle.

point along the curve. We derive a local coordinate frame with respect to the inertial frame at those points. For instance, Fig. 3-a shows how we derive coordinate frames at locations shown as dots. For the serpentine curve, a tangential line to the curve and a line normal to this tangential line is defined as the unit vectors along the local Y and X axes as −→e X and −→e Y respectively. The unit vector of the Z-axis is derived from −→e X ×

−→e Y . This information and the position vector

of the location under consideration are then used to derive the HTM at that point relative to the inertial frame. In the case of the rolling gait, due to the curve’s rotation about its longitudinal axis, the robot coordinate frame is 3D (Fig. 3-b). Utilizing these HTMs at each instance, we project the related mathematical curve onto the body coordinate frame. This step is repeated for all the subsequent taskspace curve shapes within a gait cycle. Figs. 4-(a) and (b) illustrate the spatial shapes for serpentine and rolling motions projected onto the robot coordinate frame, respectively. Next, we derive the joint-space variables for each spatial shape, such that map the SRS shape to the curves under consideration. To that end, we formulate shape matching as an optimization problem. Utilizing the kinematic model given in (2), we define 31 uniformly distributed points (10 points per soft module) along the SRS neutral axis by sampling ξ . Then we define the cost function given by

fcost =

31
∑

k=1

p(0,q,ξk)− fgait (s)

+ ∑

i, j∈{1,2,3}

l

2
i j (4)

where 0 ≤ ξk ≤ 3 and fgait is the locomotion gait shape to which the SRS is fitted, and s defines the points along fgait. The SRS concerned here are constructed from three extensible soft modules, and the latter term of (4) ensures that the optimization solution has the least total extension. This ensures the joint-space trajectories stay smooth without unnecessary length changes between solutions. We use Matlab’s global constrained optimization routine to optimize the SRS shape and save the joint-space solution. Fig. 4 shows the matched SRS shapes in thick lines. There are instances where the optimization failed. However, this has little effect on the overall joint-space trajectory due to the dense sampling of gait cycles. One may rerun the optimization routine with different initial conditions to obtain a solution. We repeat the process for all the spatial mathematical curves associated with each instance of the locomotion gaits. Fig. 5 shows the

807 joint-space trajectories for serpentine and rolling snake locomotion gait for several cycles. Note that the outward rolling trajectory is the reverse of the inward rolling trajectory. The cycle frequency of these gaits can be scaled by adjusting the cycle period. Similarly, the change of amplitude of the joint-space values results in more bending. In the case of rolling locomotion, this means a reduced rR, i.e., rolling arc radius, whereas it increases the serpentine gait’s amplitude.

IV. EXPERIMENTAL VALIDATION

A. Experimental Setup
Fig. 6a shows the overall experimental setup of the snake robot. It consists of an input pressure source, pressure controllers, pressure command interface, and the SRS. The setup’s input pressure is a constant 8 bar pressure supplied by an air compressor. The pressure to the PMAs is controlled by SMC ITV3000 series digital proportional pressure regulators and supplied via 4 mm diameter tubes. The commands to the pressure regulators are generated through a Matlab Simulink Desktop Realtime model and interfaced via a 0-10 V voltage signal using a National Instrument DAQ card. The SRS is tested on a carpeted floor, as shown in Fig. 7.
B. Testing Procedure
The SRS prototype is tested for three snake locomotion gaits; serpentine, inward rolling, and outward rolling presented in Sec. III. The joint-space trajectories given in Fig. 4 depict the length changes of PMAs. To control the pressure to PMAs, we first need to establish a mapping between the PMA pressure input and the resulting length changes. We note that the SRS needs to work with relatively fast movements to generate highly dynamic locomotion trajectories. Therefore, an empirical and static length-to-pressure mapping-based approach may result in low accuracy. We examined the PMA length changes under for 1 Hz rectified triangular wave and found that Pi j = 100li j provides acceptable results where Pi j is the pressure in bars to control the joint variable li j (i.e., length change). We tested the gait trajectories for 15 s in pressure amplitudes {1,2,3,4} bars and frequencies {0.25,0.5,0.75,1.0} Hz combinations, totaling 16 experiments per gait type. The SRS motion is captured using a fixed camera station. We applied image perspective projection [20] to track the robot movements.
C. Serpentine Motion
Fig. 7-a shows a chronological shape change of the robot for the serpentine motion at 4 bar pressure amplitude and 0.25 Hz frequency. We found that this combination replicates the best serpentine patterns. Fig. 8:A-C show how the proposed SRS behaves during serpentine motion at 2 bar-0.25 Hz, 4 bar-0.25 Hz, and 4 bar-1.00 Hz, pressure-frequency combinations. Refer to the accompanying multimedia submission for the videos of the experiments. Further, we did not observe any meaningful serpentine locomotion in the axial direction, as shown in Fig. 8:A-C. Further, it is discovered from the numbers indicated in Table I under the traveling velocity of the serpentine gait. Here, the robot

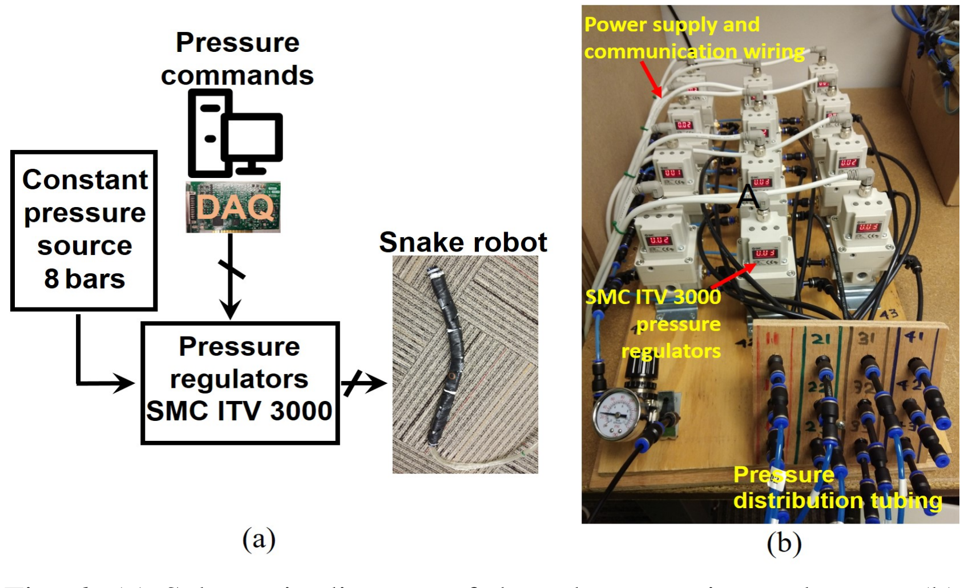
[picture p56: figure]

Fig. 6: (a) Schematic diagram of the robot experimental setup, (b) Pressure regulator assembly that control the length change of PMAs.

wobbles around without making any progress. This is a common problem with snake robots [16]. It is mainly due to insufficient friction difference in the robot skin in normal and tangential directions. In the real world, snakes have different friction coefficients in these directions. In our robot, the skin is made of a rubber surface, resulting in the same friction coefficient in all directions. Therefore the robot cannot generate a forward propagation force in the axial direction. As expected, it does not result in any forward locomotion with serpentine patterns. This is one of the main reasons why the prior work involving planer SRS [7]–[10], [12]–[15] use wheels. The wheels generate low friction in the axial direction and high friction in the normal direction.

D. Inward Rolling Motion

Fig. 7-b shows a chronological shape change of the robot during inward rolling at 4 bar actuation pressure and 1.0 Hz frequency, which stands as the best combination to illustrate inward rolling locomotion at the highest velocity. Figs. 8:D-F shows how the robot behaves during inward rolling at 2 bar-0.25 Hz, 3 bar-0.50 Hz, and 4 bar-1.00 Hz, pressure-frequency combinations. We observed that the robot could successfully replicate inward rolling locomotion at all pressure and frequency combinations except at a pressure as low as 1 bar. At 2 bar, when the moving frequency was high as 1 Hz, the robot occasionally flipped back in the opposite direction. Further, the robot shows a low bending curvature at higher actuation pressure and frequency combinations. This is mainly due to air pressure not reaching the PMAs in realtime through long pneumatic lines. In both inward and outward rolling gaits, the highest traveling velocity is observed when the applied pressure-frequency combination is at its maximum value, i.e., 4 bar-1.00 Hz (Fig. 8:F-I and Table I). The SRS’s rolling locomotion exploits 3D bending to rotate about its longitudinal axis, and this is the first time rolling locomotion is achieved by the SRS. Unlike serpentine gait, we demonstrate that SRS locomote successfully via rolling gaits. Here, the friction is applied in the rolling direction and supports rolling without interference, similar to moving a wide and continuous wheel. We observed similar performance in reverse rolling (Sec. IV-E).

808

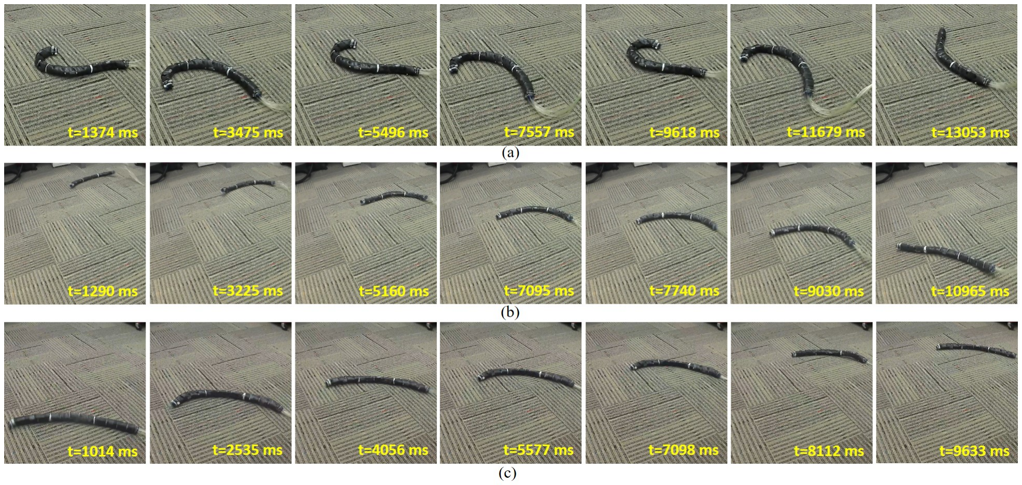
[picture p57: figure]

Fig. 7: (a) Serpentine gait at 4 bar-0.25 Hz, (b) Inward rolling and (c) Outward rolling gaits at 4 bar-1.00 Hz pressure-frequency combinations.

TABLE I: Traveling velocity of robot locomotion gaits. Velocity is
computed by dividing the mean of the X and Y displacements by the experiment time.
Pressure amplitude (bar) | Frequency (Hz) | Travelling velocity (cm/s)
Serpentine motion | Inward rolling | Outward rolling
vx | vy | vx | vy | vx | vy
1.0 | 0.25 | 0.00 | 0.00 | 0.00 | 0.00 | 0.00 | 0.00
| 0.50 | 0.00 | 0.00 | 0.00 | 0.00 | 0.00 | 0.00
| 0.75 | 0.00 | 0.00 | 0.00 | 0.00 | 0.00 | 0.00
| 1.00 | 0.00 | 0.00 | 0.00 | 0.00 | 0.00 | 0.00
2.0 | 0.25 | 0.07 | 0.13 | 1.14 | 2.21 | 0.44 | 2.20
| 0.50 | 0.12 | 0.16 | 2.11 | 3.21 | 1.29 | 2.02
| 0.75 | 0.14 | 0.21 | 2.98 | 3.99 | 2.15 | 1.82
| 1.00 | 0.08 | 0.14 | 3.43 | 4.32 | 3.01 | 1.48
3.0 | 0.25 | 0.28 | 0.43 | 3.99 | 4.87 | 3.33 | 2.08
| 0.50 | 0.49 | 0.65 | 4.05 | 5.72 | 5.69 | 0.12
| 0.75 | 0.59 | 0.71 | 5.16 | 5.89 | 4.21 | 2.19
| 1.00 | 0.28 | 0.55 | 5.23 | 7.89 | 4.89 | 1.91
4.0 | 0.25 | 0.76 | 0.36 | 3.12 | 7.55 | 4.03 | 3.91
| 0.50 | 0.63 | 0.28 | 4.16 | 9.11 | 5.79 | 2.78
| 0.75 | 0.21 | 0.27 | 4.98 | 9.67 | 6.39 | 4.55
| 1.00 | 0.09 | 0.18 | 5.61 | 10.11 | 6.56 | 6.75
E. Outward Rolling Motion

Fig. 7-c shows a chronological shape change of the robot during outward rolling motion at 4 bar actuation pressure and 1.0 Hz frequency. We found that this is the best combination to illustrate outward rolling locomotion at maximum velocity. Fig. 8:G-I show how the robot behaves during inward rolling at 2 bar-0.25 Hz, 3 bar-0.50 Hz, and 4 bar-1.00 Hz, pressure-frequency combinations. Table I shows the calculated traveling velocity of all three locomotion gaits based on image tracking results in Fig. 8. Here, the robot performs outward rolling towards opposite to its curve opening. The robot cannot perform very well as much as in the other direction. The friction is applied opposite the rolling direction, and the friction force interferes with the generated rolling thrust. This is proved by relatively low velocities recorded in Table I.

F. Discussion

The tracking results in Fig. 8 show that the SRS replicates the three locomotion gaits very well. When the actuation pressure is low at 1 bar regardless of frequency or the locomotion gait type, the robot showed almost no movements. This is mainly due to the associated 1.0-bar deadzone present in PMAs where no length change was observed and, therefore, no bending. Starting from 1.5 bar pressure, the SRS starts to replicate all locomotion gaits well. The best replication of serpentine gait is observed at 4 bar-0.25 Hz pressure-frequency combination, as presented in Fig. 7-a. At 2 bar pressure and 0.25-0.50 Hz low-frequency combinations, the SRS shows considerably slow serpentine patterns. At low frequencies, when pressure increases from 2 to 4 bar, the serpentine pattern improves. However, at higher frequencies, the pressure amplitude distorts the gait pattern replication, as presented in Fig. 8-C. This is due to these fast pressure changes not reaching PMAs in realtime through long pneumatic lines. Therefore the caused propagation delay interferes with replication patterns.

V. CONCLUSIONS
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

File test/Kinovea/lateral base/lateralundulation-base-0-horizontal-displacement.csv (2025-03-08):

Time (ms) | Head | tail
2 | 0 | 0
18 | 0,0444603 | 0,02407837
35 | 0,1029205 | -0,0212326
52 | 0,1793633 | -0,1723862
68 | 0,2653351 | -0,415451
85 | 0,3455734 | -0,7029343
102 | 0,4067726 | -0,9869537
118 | 0,4435654 | -1,236786
135 | 0,4588661 | -1,437096
152 | 0,4598885 | -1,582405
168 | 0,4536781 | -1,676407
185 | 0,4450607 | -1,729546
202 | 0,4366722 | -1,75248
218 | 0,4295959 | -1,751053
235 | 0,4239616 | -1,725029
252 | 0,4193001 | -1,673965
268 | 0,4146843 | -1,60466
285 | 0,4087677 | -1,529655
302 | 0,3999634 | -1,461899
318 | 0,3869705 | -1,410568
335 | 0,3701973 | -1,375877
352 | 0,3526917 | -1,347473
368 | 0,3376503 | -1,307617
385 | 0,3246117 | -1,237984
402 | 0,3107986 | -1,129807
418 | 0,2948494 | -0,9839859
435 | 0,2765541 | -0,800415
452 | 0,2561417 | -0,5810623
468 | 0,2359467 | -0,3460541
485 | 0,2199898 | -0,1317291
502 | 0,2107124 | 0,03009033
518 | 0,2077026 | 0,1251068
535 | 0,2090912 | 0,1585846
552 | 0,2128029 | 0,1523361
568 | 0,2168236 | 0,1320572
585 | 0,2189064 | 0,1153107
602 | 0,2160912 | 0,1112595
618 | 0,2046051 | 0,1225052
635 | 0,1812973 | 0,1419678
652 | 0,1463165 | 0,1552429
668 | 0,1036072 | 0,1499023
685 | 0,05790329 | 0,1204987
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

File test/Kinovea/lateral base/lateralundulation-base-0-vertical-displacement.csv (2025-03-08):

Time (ms) | Head | tail
2 | 0 | 0
18 | 0,02447891 | 0,6026173
35 | 0,06968307 | 1,258488
52 | 0,1489563 | 1,953648
68 | 0,257782 | 2,612173
85 | 0,3723812 | 3,155462
102 | 0,4617367 | 3,552544
118 | 0,5016518 | 3,830935
135 | 0,4819832 | 4,048826
152 | 0,4050312 | 4,242928
168 | 0,2788868 | 4,396057
185 | 0,1155167 | 4,464661
202 | -0,06805801 | 4,43561
218 | -0,2538509 | 4,342535
235 | -0,4296188 | 4,228149
252 | -0,5921974 | 4,109476
268 | -0,74506 | 3,986406
285 | -0,8929901 | 3,861197
302 | -1,039646 | 3,733267
318 | -1,188736 | 3,591988
335 | -1,346041 | 3,42857
352 | -1,519037 | 3,245947
368 | -1,710201 | 3,050968
385 | -1,90778 | 2,844263
402 | -2,088423 | 2,618706
418 | -2,232201 | 2,358421
435 | -2,331678 | 2,042212
452 | -2,389835 | 1,659218
468 | -2,415722 | 1,221178
485 | -2,420191 | 0,7562923
502 | -2,410246 | 0,2939625
518 | -2,386497 | -0,1454582
535 | -2,349455 | -0,555439
552 | -2,308811 | -0,9406586
568 | -2,279678 | -1,304514
585 | -2,266848 | -1,644585
602 | -2,257402 | -1,962868
618 | -2,227228 | -2,265675
635 | -2,152111 | -2,550449
652 | -2,019968 | -2,801905
668 | -1,840191 | -3,004017
685 | -1,639236 | -3,159544
702 | -1,444366 | -3,290262
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

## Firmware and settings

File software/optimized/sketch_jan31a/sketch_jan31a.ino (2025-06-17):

#include <WiFi.h>
#include <WebServer.h>
#include <ESP32Servo.h>
#include <esp_now.h>
#include <math.h>

WebServer server(80);

// ESP-NOW data structure
typedef struct struct_message {
  float heading;
  float gyroX;
  float gyroY;
  float gyroZ;
  unsigned long timestamp;
} struct_message;

struct_message receivedData;

// ============================================
// PWM CONFIGURATION 
// ============================================
const int PWM_FREQ = 50;         // 50Hz for servo control
const int PWM_RESOLUTION = 16;   // 16-bit resolution
const int PWM_CHANNEL = 0;       // PWM channel for rattle

// Servo configuration
const int NUM_SERVOS = 10;
const int NUM_HORIZONTAL = 7;
const int servoLayout[NUM_SERVOS] = {1, 0, 1, 1, 0, 1, 1, 0, 1, 1};
const int servoPins[NUM_SERVOS] = {23, 22, 2, 4, 16, 17, 5, 18, 19, 21};

// Enhanced Rattling configuration
const int tailLiftIdx = 7;
const int tailRattle1Idx = 9;

bool rattlingActive = false;
unsigned long rattlingStart = 0;
unsigned long RATTLING_DURATION = 5000;
float RATTLING_FREQ = 80.0;
float RATTLING_AMPLITUDE = 21.0;
float RATTLE_LIFT_ANGLE = 45.0;
const float CURL_AMPLITUDE = 70.0;
bool bodyHasCurled = false;
unsigned long lastRattleUpdate = 0;
const int RATTLE_UPDATE_INTERVAL = 5;

Servo servos[NUM_SERVOS];

// Locomotion parameters
bool locomotionEnabled = false;
bool forwardDirection = true;
int movementMode = 0;
float amplitude = 30.0;
float frequency = 1.0;
float phaseOffset = 60.0;
float verticalAmplitude = 20.0;
float verticalPhaseOffset = 90.0;
float centerPosition = 90.0;
unsigned long lastUpdate = 0;
const int interval = 20;

// Servo test variables
bool testingActive = false;
int testServoIndex = 0;
int testPosition = 0;
unsigned long lastTestMillis = 0;

// ============================================
// FIXED GYROSCOPE VARIABLES WITH STATE TRACKING
// ============================================
float gyroX_offset = 0.0;
float gyroY_offset = 0.0;
float gyroZ_offset = 0.0;

// More sensitive thresholds for compass-calculated gyro
float GYRO_THRESHOLD_X = 3.0;   // Reduced further for better sensitivity
float GYRO_THRESHOLD_Y = 5.0;   // Reduced further for better sensitivity  
float GYRO_THRESHOLD_Z = 170.0;  // Reduced for easier rattle trigger
unsigned long MIN_MOVE_TIME = 200;  // Reduced for faster response
bool GYRO_CONTROL_ENABLED = false;

// Calibration process variables
bool isCalibrating = false;
int calibrationSamples = 0;
const int MAX_CALIBRATION_SAMPLES = 30; // Faster calibration
float calibrationSumX = 0;
float calibrationSumY = 0;
float calibrationSumZ = 0;

// Motion detection variables with state tracking
unsigned long moveStartTime = 0;
float lastGyroX = 0, lastGyroY = 0, lastGyroZ = 0;
unsigned long lastGyroUpdate = 0;
const unsigned long GYRO_TIMEOUT = 3000;

// ============================================
// STATE TRACKING VARIABLES
// ============================================
String currentMovementState = "IDLE";
String lastDetectedMovement = "NONE";
float currentGyroMagnitude = 0.0;
bool movementActive = false;
unsigned long lastMovementTime = 0;
int movementCounter = 0;

// Movement detection counters for debugging
int forwardDetections = 0;
int backwardDetections = 0;
int leftDetections = 0;
int rightDetections = 0;
int rattleDetections = 0;

// ESP-NOW callback function with enhanced state tracking
void OnDataRecv(const esp_now_recv_info_t *recv_info, const uint8_t *incomingData, int len) {
  if (len == sizeof(receivedData)) {
    memcpy(&receivedData, incomingData, sizeof(receivedData));
    
    lastGyroUpdate = millis();
    processGyroscopeData(receivedData.gyroX, receivedData.gyroY, receivedData.gyroZ);
    
    // Update current gyro magnitude for state display
    currentGyroMagnitude = sqrt(pow(lastGyroX, 2) + pow(lastGyroY, 2) + pow(lastGyroZ, 2));
  }
}

// ============================================
// IMPROVED GYROSCOPE FUNCTIONS
// ============================================

void startGyroCalibration() {
  Serial.println("🔧 ========================================");
  Serial.println("🔧 STARTING ENHANCED GYROSCOPE CALIBRATION");
  Serial.println("🔧 ========================================");
  
  isCalibrating = true;
  calibrationSamples = 0;
  calibrationSumX = 0;
  calibrationSumY = 0;
  calibrationSumZ = 0;
  
  // Stop any current snake movement during calibration
  locomotionEnabled = false;
  rattlingActive = false;
  testingActive = false;
  currentMovementState = "CALIBRATING";
  centerAllServos();
  
  Serial.printf("📊 Keep device PERFECTLY STILL for %d samples (about 3 seconds)\n", MAX_CALIBRATION_SAMPLES);
  Serial.println("🔧 ========================================");
}

void processCalibrationSample(float gx, float gy, float gz) {
  if (!isCalibrating) return;
  
  calibrationSumX += gx;
  calibrationSumY += gy;
  calibrationSumZ += gz;
  calibrationSamples++;
  
  // Progress feedback
  if (calibrationSamples % 5 == 0) {
    Serial.printf("📊 Calibration: %d/%d samples (%.0f%%) - Current: X:%.2f Y:%.2f Z:%.2f\n", 
                  calibrationSamples, MAX_CALIBRATION_SAMPLES, 
                  (calibrationSamples * 100.0) / MAX_CALIBRATION_SAMPLES,
                  gx, gy, gz);
  }
  
  if (calibrationSamples >= MAX_CALIBRATION_SAMPLES) {
    // Calculate offsets
    gyroX_offset = calibrationSumX / calibrationSamples;
    gyroY_offset = calibrationSumY / calibrationSamples;
    gyroZ_offset = calibrationSumZ / calibrationSamples;
    
    isCalibrating = false;
    currentMovementState = "IDLE";
    
    Serial.println("✅ ========================================");
    Serial.println("✅ GYROSCOPE CALIBRATION COMPLETE!");
    Serial.printf("📊 Calculated offsets: X:%.3f Y:%.3f Z:%.3f\n", 
                  gyroX_offset, gyroY_offset, gyroZ_offset);
    Serial.printf("🎯 Active thresholds: X:%.1f Y:%.1f Z:%.1f°/s\n",
                  GYRO_THRESHOLD_X, GYRO_THRESHOLD_Y, GYRO_THRESHOLD_Z);
    Serial.println("✅ ========================================");
  }
}

void processGyroscopeData(float gx, float gy, float gz) {
  // If calibrating, add to calibration samples
  if (isCalibrating) {
    processCalibrationSample(gx, gy, gz);
    return;
  }
  
  // Apply calibration offsets
  float calibratedX = gx - gyroX_offset;
  float calibratedY = gy - gyroY_offset;
  float calibratedZ = gz - gyroZ_offset;
  
  // Store for web UI display
  lastGyroX = calibratedX;
  lastGyroY = calibratedY;
  lastGyroZ = calibratedZ;
  
  // Always log the values for debugging (every 20 samples to avoid spam)
  static int debugCounter = 0;
  if (debugCounter++ % 20 == 0) {
    Serial.printf("🎯 Gyro Debug: X:%.2f Y:%.2f Z:%.2f | Thresholds: X:%.1f Y:%.1f Z:%.1f | Control:%s\n",
                  calibratedX, calibratedY, calibratedZ,
                  GYRO_THRESHOLD_X, GYRO_THRESHOLD_Y, GYRO_THRESHOLD_Z,
                  GYRO_CONTROL_ENABLED ? "ON" : "OFF");
  }
  
  // Check if gyro control is enabled
  if (!GYRO_CONTROL_ENABLED) {
    currentMovementState = "GYRO_DISABLED";
    return;
  }
  
  // FIXED: Better movement detection logic
  bool xActive = fabs(calibratedX) > GYRO_THRESHOLD_X;
  bool yActive = fabs(calibratedY) > GYRO_THRESHOLD_Y;
  bool zActive = fabs(calibratedZ) > GYRO_THRESHOLD_Z;
  
  bool anyMovement = xActive || yActive || zActive;
  
  if (anyMovement) {
    if (moveStartTime == 0) {
      moveStartTime = millis();
      
      // FIXED: Determine movement based on STRONGEST axis, not just any active axis
      float absX = fabs(calibratedX);
      float absY = fabs(calibratedY);
      float absZ = fabs(calibratedZ);
      
      String detectedMovement = "UNKNOWN";
      
      // FIXED: Only trigger rattle if Z is DOMINANT and above threshold
      if (zActive && absZ > absX && absZ > absY && absZ > (GYRO_THRESHOLD_Z + 2.0)) {
        detectedMovement = "RATTLE";
        rattleDetections++;
        Serial.printf("🐍 RATTLE DETECTED: Z=%.2f (threshold=%.1f, dominant over X=%.2f Y=%.2f)\n", 
                      absZ, GYRO_THRESHOLD_Z, absX, absY);
      } 
      // FIXED: Better axis priority logic
      else if (yActive && absY > absX && absY > absZ) {
        if (calibratedY > 0) {
          detectedMovement = "FORWARD";
          forwardDetections++;
          Serial.printf("⬆️ FORWARD DETECTED: Y=%.2f (positive, dominant)\n", calibratedY);
        } else {
          detectedMovement = "LEFT";
          leftDetections++;
          Serial.printf("⬅️ LEFT DETECTED: Y=%.2f (negative, dominant)\n", calibratedY);
        }
      } 
      else if (xActive && absX > absY && absX > absZ) {
        if (calibratedX > 0) {
          detectedMovement = "RIGHT";
          rightDetections++;
          Serial.printf("➡️ RIGHT DETECTED: X=%.2f (positive, dominant)\n", calibratedX);
        } else {
          detectedMovement = "BACKWARD";
          backwardDetections++;
          Serial.printf("⬇️ BACKWARD DETECTED: X=%.2f (negative, dominant)\n", calibratedX);
        }
      }
      // FIXED: If movement detected but not dominant enough, ignore
      else {
        Serial.printf("🔍 Movement detected but not dominant enough - X:%.2f Y:%.2f Z:%.2f\n", 
                      absX, absY, absZ);
        moveStartTime = 0; // Reset immediately
        return;
      }
      
      lastDetectedMovement = detectedMovement;
      currentMovementState = "DETECTING_" + detectedMovement;
    }
    
    // Check if movement has been sustained long enough
    if (millis() - moveStartTime >= MIN_MOVE_TIME) {
      triggerMovement(lastDetectedMovement, calibratedX, calibratedY, calibratedZ);
      movementActive = true;
      lastMovementTime = millis();
      movementCounter++;
    }
  } else {
    // Reset movement detection
    if (moveStartTime != 0) {
      Serial.printf("🔄 Movement ended after %lu ms (not sustained enough)\n", millis() - moveStartTime);
    }
    moveStartTime = 0;
    movementActive = false;
    if (!locomotionEnabled && !rattlingActive && !testingActive) {
      currentMovementState = "IDLE";
    }
  }
}

void setupRattlePWM() {
  Serial.println("🐍 Setting up enhanced PWM for high-speed rattling...");
  
  // Use new ESP32 Core 3.x LEDC functions
  ledcAttach(servoPins[tailRattle1Idx], PWM_FREQ, PWM_RESOLUTION);
  
  Serial.printf("✅ PWM configured: Pin %d, Freq %dHz, Resolution %d-bit\n", 
                servoPins[tailRattle1Idx], PWM_FREQ, PWM_RESOLUTION);
}
void triggerMovement(String movement, float gx, float gy, float gz) {
  Serial.println("🚀 ========================================");
  Serial.printf("🚀 TRIGGERING MOVEMENT: %s\n", movement.c_str());
  Serial.printf("🚀 Gyro values: X:%.2f Y:%.2f Z:%.2f\n", gx, gy, gz);
  
  // Stop current movement first
  locomotionEnabled = false;
  
  if (movement == "RATTLE") {
    Serial.println("🐍 >>> ACTIVATING RATTLE ATTACK!");
    currentMovementState = "RATTLING";
    rattleTail();
  } else if (movement == "FORWARD") {
    Serial.println("⬆️ >>> ACTIVATING FORWARD MOTION");
    currentMovementState = "MOVING_FORWARD";
    movementMode = 0; // Lateral undulation
    forwardDirection = true;
    locomotionEnabled = true;
  } else if (movement == "BACKWARD") {
    Serial.println("⬇️ >>> ACTIVATING BACKWARD MOTION");
    currentMovementState = "MOVING_BACKWARD";
    movementMode = 0; // Lateral undulation
    forwardDirection = false;
    locomotionEnabled = true;
  } else if (movement == "LEFT") {
    Serial.println("⬅️ >>> ACTIVATING LEFT SIDEWINDING");
    currentMovementState = "MOVING_LEFT";
    movementMode = 1; // Sidewinding
    forwardDirection = false;
    locomotionEnabled = true;
  } else if (movement == "RIGHT") {
    Serial.println("➡️ >>> ACTIVATING RIGHT SIDEWINDING");
    currentMovementState = "MOVING_RIGHT";
    movementMode = 1; // Sidewinding
    forwardDirection = true;
    locomotionEnabled = true;
  }
  
  Serial.println("🚀 ========================================");
}
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
void loop() {
  server.handleClient();
  
  // Check enhanced gyro timeout
  if (GYRO_CONTROL_ENABLED && (millis() - lastGyroUpdate > GYRO_TIMEOUT)) {
    if (currentMovementState != "GYRO_TIMEOUT") {
      Serial.println(">>> 🎯 ENHANCED GYRO TIMEOUT - Stopping movement");
      currentMovementState = "GYRO_TIMEOUT";
    }
    locomotionEnabled = false;
    centerAllServos();
  }
  
  // Priority-based enhanced servo control
  if (rattlingActive) {
    updateTailRattle();
  } else if (testingActive) {
    handleServoTest();
  } else if (locomotionEnabled && (millis() - lastUpdate >= interval)) {
    if (movementMode == 0) {
      updateServosLateralUndulation();
    } else {
      updateServosSidewinding();
    }
    lastUpdate = millis();
  }
  
  // Update movement state based on current activity
  if (!rattlingActive && !testingActive && !locomotionEnabled && 
      GYRO_CONTROL_ENABLED && currentMovementState.indexOf("MANUAL_") == -1 && 
      currentMovementState != "GYRO_TIMEOUT") {
    currentMovementState = "IDLE";
  }
  
  // Yield to prevent watchdog issues
  yield();
}

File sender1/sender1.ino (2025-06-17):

#include <WiFi.h>
#include <esp_now.h>
#include <QMC5883LCompass.h>

QMC5883LCompass compass;

// ESP-NOW setup
uint8_t snakeAddress[] = {0x34, 0x94, 0x54, 0xAA, 0x4E, 0x70}; // Snake MAC address

// Command structure to send to snake
typedef struct struct_command {
  String command;
  unsigned long timestamp;
  int intensity; // For rattle intensity or movement speed
} struct_command;

struct_command snakeCommand;

// Calibration variables
int baseX = 0, baseY = 0, baseZ = 0;
bool isCalibrated = false;

// Movement detection thresholds (from your working logic)
const int LEFT_THRESHOLD_Y = 800;   
const int RIGHT_THRESHOLD_Y = 800;  // Same as left since we use direction logic
const int RATTLE_THRESHOLD_X = 1500;

// Detection window variables
struct MovementWindow {
  int minX, maxX, minY, maxY, minZ, maxZ;
  unsigned long startTime;
  bool active;
  int lastX, lastY, lastZ;
};

MovementWindow window = {0, 0, 0, 0, 0, 0, 0, false, 0, 0, 0};

const unsigned long DETECTION_WINDOW = 1000; // 1 second window
const int MOVEMENT_START_THRESHOLD = 100;

// ESP-NOW callback
void OnSent(const uint8_t *mac_addr, esp_now_send_status_t status) {
  Serial.print("📡 Command sent: ");
  Serial.println(status == ESP_NOW_SEND_SUCCESS ? "✅ SUCCESS" : "❌ FAILED");
}

void sendCommandToSnake(String cmd, int intensity = 1) {
  snakeCommand.command = cmd;
  snakeCommand.timestamp = millis();
  snakeCommand.intensity = intensity;
  
  Serial.printf("📤 Sending command: %s (intensity: %d)\n", cmd.c_str(), intensity);
  
  esp_err_t result = esp_now_send(snakeAddress, (uint8_t *)&snakeCommand, sizeof(snakeCommand));
  
  if (result == ESP_OK) {
    Serial.println("✅ Command transmission initiated");
  } else {
    Serial.printf("❌ Send error: %d\n", result);
  }
}

void calibrateCompass() {
  Serial.println("🔧 ========================================");
  Serial.println("🔧 CALIBRATING COMPASS - KEEP STILL!");
  Serial.println("🔧 ========================================");
  
  long sumX = 0, sumY = 0, sumZ = 0;
  const int samples = 50;
  
  for (int i = 0; i < samples; i++) {
    compass.read();
    sumX += compass.getX();
    sumY += compass.getY();
    sumZ += compass.getZ();
    
    if (i % 10 == 0) {
      Serial.printf("📊 Calibration: %d/%d\n", i, samples);
    }
    delay(50);
  }
  
  baseX = sumX / samples;
  baseY = sumY / samples;
  baseZ = sumZ / samples;
  isCalibrated = true;
  
  Serial.println("✅ CALIBRATION COMPLETE!");
  Serial.printf("📊 Base: X=%d, Y=%d, Z=%d\n", baseX, baseY, baseZ);
  Serial.println("🔧 ========================================");
}

String detectMovement(int calX, int calY, int calZ) {
  unsigned long now = millis();
  
  // Check if significant movement started
  if (!window.active) {
    int deltaX = abs(calX - window.lastX);
    int deltaY = abs(calY - window.lastY);
    int deltaZ = abs(calZ - window.lastZ);
    
    if (deltaX > MOVEMENT_START_THRESHOLD || deltaY > MOVEMENT_START_THRESHOLD || deltaZ > MOVEMENT_START_THRESHOLD) {
      // Start detection window
      window.active = true;
      window.startTime = now;
      window.minX = window.maxX = calX;
      window.minY = window.maxY = calY;
      window.minZ = window.maxZ = calZ;
      
      Serial.println("🎯 Movement detection started...");
    }
  }
  
  if (window.active) {
    // Update ranges
    window.minX = min(window.minX, calX);
    window.maxX = max(window.maxX, calX);
    window.minY = min(window.minY, calY);
    window.maxY = max(window.maxY, calY);
    window.minZ = min(window.minZ, calZ);
    window.maxZ = max(window.maxZ, calZ);
    
    // Check if window is complete
    if (now - window.startTime >= DETECTION_WINDOW) {
      int rangeX = window.maxX - window.minX;
      int rangeY = window.maxY - window.minY;
      int rangeZ = window.maxZ - window.minZ;
      
      Serial.printf("🔍 Analysis: X-range=%d, Y-range=%d, Z-range=%d\n", 
                    rangeX, rangeY, rangeZ);
      
      String result = "NONE";
      
      // Check rattle first (highest priority)
      if (rangeX > RATTLE_THRESHOLD_X) {
        result = "RATTLE";
        Serial.println("🐍 RATTLE DETECTED!");
      }
      // Check left/right movements
      else if (rangeY > LEFT_THRESHOLD_Y) {
        if (window.minY < -400) { // Left movement goes into negative Y territory
          result = "LEFT";
          Serial.printf("⬅️ LEFT MOVEMENT DETECTED! (Y-range=%d, min=%d)\n", rangeY, window.minY);
        } else if (window.maxY > 800) { // Right movement stays in positive Y territory
          result = "RIGHT";
          Serial.printf("➡️ RIGHT MOVEMENT DETECTED! (Y-range=%d, max=%d)\n", rangeY, window.maxY);
        }
      }
      else {
        Serial.printf("❌ Movement too small - ignored (X=%d, Y=%d, Z=%d)\n", 
                     rangeX, rangeY, rangeZ);
      }
      
      // Reset window
      window.active = false;
      return result;
    }
  }
  
  // Update last values
  window.lastX = calX;
  window.lastY = calY; 
  window.lastZ = calZ;
  
  return "DETECTING";
}
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

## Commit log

2025-01-29 added 3D files and esp arduino code
    [Body1.stl, Bottom-head.stl, V2-reverse.stl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]
2025-01-31 added servo centering function
2025-01-31 added old stm32 code
2025-01-31 added scales design
    [Passive_Scales.stl]
2025-02-05 added new stl designs and an optimized test code
    [scales-scaled.stl]
2025-02-05 fix servo oriantation
2025-02-10 added current sensor, and logging functionality
2025-02-14 updated latex and stl files names
    [Vertical-holder.stl, bottom-head.stl, horizontal-holder.stl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]
2025-02-26 fixed the undulation direction
    [sketch_jan31a.ino]
2025-03-03 added kinovea test results
    [horizonalspeed.csv, horizontal deviation.csv, horizontal displacement.csv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]
2025-03-06 added power consumption data
    [idle_data.csv, lateal_undulation_scales.csv, lateral_wheel.csv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]
2025-03-06 added test data combined
    [combined_lateral_base.csv, combined_lateral_scales.csv, combined_lateral_wheels.csv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]
2025-03-06 test data
    [combined_lateral_base.csv, combined_lateral_scales.csv, combined_lateral_wheels.csv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]
2025-03-07 added multiple experiments
    [combined_sidewinding_scales.csv, idle.csv, idle1.csv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]
2025-03-08 new test results with many tries
    [Merged_Lateral_Base_Data.csv, Merged_Lateral_Scales_Data.csv, Merged_Lateral_Wheels_Data.csv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]
2025-03-08 current logs updated
    [Merged_Lateral_Base_Data.csv, Merged_Lateral_Scales_Data.csv, Merged_Lateral_Wheels_Data.csv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]
2025-03-08 add Kinovea analysis
    [Final_Lateral_Base_DataFrame_with_Max_Time.csv, Final_Lateral_Wheel_DataFrame_with_Max_Time.csv, Final_Merged_DataFrame_with_Max_Time.csv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]
2025-03-08 added the Kinovea extracted data
    [lateral base.csv, lateral scales.csv, lateral wheels.csv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]
2025-03-09 updated combined data
    [lateral base.csv, lateral scales.csv, lateral wheels.csv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]
2025-03-09 added the react code to visualize the Kinovea data in graphs
    [combined_lateral_base.csv, combined_lateral_scales.csv, combined_lateral_wheels.csv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]
2025-06-17 addded espnow connection to gyroscope
2025-06-17 code for gathering sensor info
2025-06-17 fixed the senders code
    [sender1.ino, sketch_jan31a.ino, testing.ino]
